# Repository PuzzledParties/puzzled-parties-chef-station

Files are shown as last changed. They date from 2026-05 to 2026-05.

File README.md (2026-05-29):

# Puzzled Parties Chef Station

Chef Station is the hardware/software project for interactive kitchen-game
features. The current build includes the shared power/network layout, the
Master Controller ESP32, and the Simon, chopping, pan motion, pot temperature,
and garnish placement modules.

GitHub is the source of truth for the project: tasks live in Issues, work happens on branches, reviews happen through Pull Requests, and build decisions live in `docs/decisions`.

## Current Build

- Waveshare ESP32-P4-POE-ETH controller board. This is the default board for
  Chef Station unless a future note explicitly says otherwise.
- Four illuminated arcade buttons labeled Ingredient 1 through Ingredient 4.
- One MOSFET low-side lamp driver per button.
- One 1k gate resistor and one 10k gate pulldown per MOSFET.
- Shared lamp positive rail for the button LEDs.
- Common ground rail with local ground buses for each button channel.
- Onboard ES8311 codec and NS4150B speaker amplifier on the Waveshare board.
- One 8 ohm / 2W speaker connected to the Waveshare MX1.25 2-pin speaker header.

## Repo Layout

```text
hardware/
  fritzing/              Editable Fritzing sketches, exports, downloaded parts
  wiring-checklists/     Wiring checklists and legacy notes

firmware/
  esp32-chef-station/    ESP32 firmware home

docs/
  build-notes/           Running notes from assembly/testing
  decisions/             Decision records for hardware/software choices
  collaborator-setup.md  How collaborators get started
  project-management.md  How we use GitHub/Codex to manage work

tools/
  diagram-generators/    Scripts that generate/edit diagram assets
```

## Main Files

- `docs/build-wiring-diagrams.md` - iPad-friendly index of the build wiring diagrams, checklists, and editable Fritzing files.
- `hardware/fritzing/master-power-network/` - master power and network layout.
- `hardware/fritzing/library-art/chef_station_simon_4btn_audio_editable.fzz` - current editable Fritzing sketch.
- `hardware/fritzing/library-art/chef_station_simon_4btn_audio_editable.png` - current PNG preview.
- `hardware/fritzing/library-art/fritzing_svg_export/chef_station_simon_4btn_audio_editable_breadboard.svg` - current Fritzing SVG export.
- `hardware/fritzing/library-art/wiring_checklist_4btn_audio.md` - current wiring checklist.
- `hardware/fritzing/chopping-module/` - chopping module wiring.
- `hardware/fritzing/pan-motion-cooktop/` - pan motion cooktop wiring.
- `hardware/fritzing/pot-temperature-heat-balance/` - pot temperature / heat balance wiring.
- `hardware/fritzing/garnish-placement/` - garnish placement wiring.
- `tools/diagram-generators/generate_orthogonal_fritzing_diagram.py` - generator for the latest native Fritzing sketch.

## Important Electrical Notes

- All grounds must be common: ESP32-P4 GND, lamp supply negative, button switch grounds, MOSFET sources, and pulldown grounds.
- The linked illuminated arcade buttons are treated as 12V LED buttons.
- Button inputs use ESP32-P4 internal pullups: unpressed = HIGH, pressed = LOW.
- Lamp gates use GPIO20, GPIO21, GPIO22, and GPIO23. Avoid GPIO24/GPIO25 for lamps because the Waveshare header labels them as USB `D-`/`D+`.
- Audio uses the onboard ES8311 codec and NS4150B amplifier. Connect the speaker only to the board speaker header; do not tie either speaker lead to ground.
- IRFB11N50APBF is overkill and not logic-level; replace with a logic-level MOSFET if the button LEDs do not fully turn on.

## Daily Workflow

1. Pick or create a GitHub Issue.
2. Create a branch named for the work, such as `firmware/simon-game` or `hardware/audio-test`.
3. Make the change locally.
4. Push the branch and open a Pull Request.
5. Merge into `main` after review or test notes are captured.

## Regenerating The Current Wiring Diagram

Run from the repo root:

```powershell
python .\tools\diagram-generators\generate_orthogonal_fritzing_diagram.py
```

The script writes the editable `.fzz` and asks Fritzing to export SVGs through:

```powershell
& 'C:\Program Files\Fritzing\Fritzing.exe' -svg .\hardware\fritzing\library-art\fritzing_svg_export
```

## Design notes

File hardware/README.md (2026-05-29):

# Hardware

Hardware assets for Chef Station.

## Current Diagram

- Build wiring index: [`../docs/build-wiring-diagrams.md`](../docs/build-wiring-diagrams.md)
- Master power and network: `fritzing/master-power-network/`
- Simon ingredient buttons and audio: `fritzing/library-art/`
- Chopping module: `fritzing/chopping-module/`
- Pan motion cooktop: `fritzing/pan-motion-cooktop/`
- Pot temperature / heat balance: `fritzing/pot-temperature-heat-balance/`
- Garnish placement: `fritzing/garnish-placement/`

## Areas

- `fritzing/` - editable diagrams, Fritzing exports, downloaded parts, and older diagram iterations.
- `wiring-checklists/` - wiring checklist history and notes.

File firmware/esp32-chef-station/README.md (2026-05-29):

# ESP32 Chef Station Firmware

Firmware home for Chef Station.

Planned modules:

- Button input scanning with `INPUT_PULLUP`.
- Lamp output control for Simon-style flashing.
- Audio output on GPIO26 using DAC or PWM into the PAM8403 `L IN`.
- Game state for Simon and future Chef Station features.

No firmware implementation has been committed yet.

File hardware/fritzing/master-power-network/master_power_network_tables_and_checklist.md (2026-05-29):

# Chef Station Master Power And Network Tables / Checklist

## Power Rail Table

| Rail | Source | Voltage | Use | Hard rule |
|---|---|---:|---|---|
| PoE | LS108GP switch ports | PoE | ESP32 controller boards only | Do not power LED strips, servos, lamps, or amplifiers from ESP32 PoE boards. |
| 12V_SHOW | 12V Adapter A | 12V DC | Actual 12V LED strips, 12V amplifier, fans, monitor accessory if rated 12V | Only connect devices explicitly rated for 12V. Do not tie to other adapter positives. |
| 5V_LED | 12V Adapter B -> Buck #2 | 5.0V-5.1V DC | WS2812/NeoPixel strips, cooktop coil LEDs, overhead strip, 5V Simon button lamps | Do not parallel with another buck output. |
| 5V_AUDIO_SERVO | 12V Adapter C -> Buck #3 | 5.0V-5.1V DC | DFPlayer modules, small amplifiers, small speakers, servo timer, optional LCD backlights | Do not feed from ESP32 5V/PoE board power. |
| 5V_AUX | 12V Adapter D -> Buck #1 | 5.0V-5.1V DC | Optional LCD backlights, small non-PoE accessories, low-current status LEDs, small relay boards | Keep low-current and isolated from other 5V positives. |
| COMMON_GND | Ground terminal block / bus | 0V reference | Shared reference where GPIO/data/control crosses rails | Do not route load return current through ESP32 ground pins. |

## Network Port Table

| LS108GP port | Device | Cable behavior | Power behavior |
|---|---|---|---|
| 1 | Simon ESP32 PoE board | Ethernet network | PoE powers ESP32 controller only. |
| 2 | Chopping ESP32 PoE board | Ethernet network | PoE powers ESP32 controller only. |
| 3 | Pan Motion ESP32 PoE board | Ethernet network | PoE powers ESP32 controller only. |
| 4 | Pot Temperature ESP32 PoE board | Ethernet network | PoE powers ESP32 controller only. |
| 5 | Garnish Placement ESP32 PoE board | Ethernet network | PoE powers ESP32 controller only. |
| 6 | Master Controller ESP32 PoE board | Ethernet network | PoE powers ESP32 controller only. |
| 7 | Epson TM-T20IV / TM-T20V-family printer | Ethernet network | Separate Epson manufacturer power supply. Not PoE. |
| 8 | Optional router/DHCP source or spare | DHCP/network management if needed | Router uses its own power if used. |

## Per-Module Accessory Power Table

| Module | ESP32 power/network | Accessory power | Control/ground notes |
|---|---|---|---|
| Simon | PoE over Ethernet | Button lamps from 5V_LED or 12V_SHOW by lamp rating; audio if present from 5V_AUDIO_SERVO | Button switches to ESP32 GPIO/GND. Lamp MOSFET sources to COMMON_GND. ESP32 GPIOs drive MOSFET gates only. |
| Chopping | PoE over Ethernet | Piezo from ESP32 3.3V if suitable; I2C LCD backlight from 5V_AUX or 5V_LED | Use optional I2C level shifter for 5V I2C LCD. LCD/piezo ground common with ESP32. |
| Pan Motion | PoE over Ethernet | Hall sensors from ESP32 3.3V; cooktop LED from 5V_LED or 12V_SHOW by strip type; DFPlayer/audio from 5V_AUDIO_SERVO | ESP32 sends LED data and serial to DFPlayer. All grounds common. |
| Pot Temperature | PoE over Ethernet | Encoder on ESP32 GPIO; cooktop LED from 5V_LED or 12V_SHOW; temp strip/ring from 5V_LED | Encoder uses INPUT_PULLUP. ESP32 and LED rail grounds common. |
| Garnish Placement | PoE over Ethernet | Touch electrodes only to ESP32 touch pins through 1k resistors; RGB strip from 5V_LED; servo from 5V_AUDIO_SERVO | DONE button to ESP32 GPIO/GND. ESP32, servo, and LED grounds common. |
| Master Controller | PoE over Ethernet | Start Game button only; Epson printer is Ethernet | GPIO5 to one side of the Start Game button, other side to GND. Configure GPIO5 with INPUT_PULLUP. |

## Master Controller ESP32 Pin Map

| Function | Master Controller ESP32 connection | Destination | Notes |
|---|---|---|---|
| Power/network | RJ45 Ethernet / PoE | LS108GP port 6 | PoE powers the ESP32 controller only. |
| Start Game button signal | GPIO5 | One side of momentary normally-open Start Game button | `INPUT_PULLUP`; unpressed = HIGH, pressed = LOW. |
| Start Game button ground | GND | Other side of Start Game button / COMMON_GND | This is the only local GPIO wiring on the Master Controller ESP32. |
| Module commands and score replies | Ethernet UDP port 42100 | Simon, chopping, pan, pot-temp, and garnish ESP32 boards | No GPIO start/reset harness between controller and modules. |
| Receipt printer | Ethernet TCP port 9100 | Epson TM-T20IV / TM-T20V-family printer | Printer uses its own Epson power supply; no ESP32 GPIO pins. |

## Grounding Notes

- All grounds must be common where GPIO/data/control signals cross between PoE ESP32 boards and external 5V/12V accessories.
- Connect Adapter A/B/C/D negatives, Buck #1/#2/#3 grounds, LED strip ground, DFPlayer/audio ground, servo ground, Simon lamp ground, and any relevant ESP32 GND pins to COMMON_GND.
- Module commands travel over Ethernet, so no separate GPIO sync harness is required for module start/reset.
- Do not route high-current LED, servo, or audio return current through ESP32 ground pins. Use a ground terminal block or bus.
- Grounds may be common; separate 12V positives and separate buck 5V positives must not be tied together.

## Setup Checklist

- Verify every adapter output with a multimeter before connecting electronics.
- Tape or lock adjustable adapter selector dials at 12V.
- Adjust buck converters to 5.0V-5.1V before connecting 5V electronics.
- Label both ends of every power cable.
- Confirm 12V_SHOW never touches 5V devices.
- Confirm 5V rails never touch ESP32 3.3V pins.
- Keep each 12V adapter as its own limited-current branch.
- Do not parallel separate wall adapter outputs.
- Do not parallel separate buck converter outputs.
- Use proper wire gauge for LED, servo, and audio currents.
- Avoid breadboard rails for multi-amp loads.
- Add 1000uF across LED strip 5V/GND near strip input.
- Add 470uF-1000uF near servo power.
- Add 470uF-1000uF near DFPlayer/audio modules.
- Add 0.1uF near Hall, piezo, and small sensor modules.
- Add a 330-470 ohm resistor on each WS2812 data line.
- If no fuses are available, avoid the 5V/60A open-frame supply in this temporary build.

## Warning Callouts

- PoE budget: keep total ESP32 PoE load under the LS108GP 62W budget and 30W per-port max.
- Common ground: required wherever GPIO/data/control signals cross between ESP32 boards and external accessory power rails.
- 12V vs 5V separation: only 12V-rated devices connect to 12V_SHOW; 5V devices connect only to named buck-derived 5V rails.
- No high-current loads from ESP32 PoE boards: ESP32 GPIOs send signals only.
- No unfused 60A supply in the temporary build: add fused distribution before using any large open-frame supply.
- Do not parallel buck outputs.
- Verify adjustable adapters with a multimeter.

## Network Behavior Notes

- ESP32 modules can receive IP addresses from a router/DHCP source or use static IPs.
- If there is no router, create and label a static IP plan before the event.
- The Master Controller ESP32 communicates with modules over Ethernet.
- The Epson printer is addressed by IP.
- The LS108GP may be unmanaged; use an optional router/DHCP source if network management is needed.
- Do not rely on internet access during the event.

## Assumptions And Substitutions

- The master controller in this build is a Waveshare ESP32-P4-POE-ETH / NH board.
- Hardware START_SYNC / RESET_SYNC wiring is intentionally omitted. Module start/reset/score traffic is planned over Ethernet.
- Exact LS108GP and Waveshare ESP32-P4-POE-ETH/NH Fritzing parts were not available in the installed library, so the sketch embeds custom editable helper parts with labeled connectors.
- No third-party parts were downloaded.
- The diagram is a master power/network layout, not a PCB fabrication footprint.

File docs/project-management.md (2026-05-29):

# Project Management

Use this repository as the project home for Chef Station.

## GitHub

- Issues are the task list.
- Branches are where work happens.
- Pull Requests are where changes get reviewed, tested, and merged.
- Decision records in `docs/decisions` explain why we chose a hardware/software direction.
- Build notes in `docs/build-notes` capture messy real-world findings while assembling and testing.

## Suggested Issue Labels

- `hardware` - wiring, components, panel layout, enclosure, soldering.
- `firmware` - ESP32 code, game state, audio, inputs, outputs.
- `docs` - checklists, setup guides, decisions.
- `test` - bench testing, validation, measurements.
- `question` - unresolved design choice.
- `bug` - something that used to work or should work but does not.

## Branch Names

Use short, descriptive names:

```text
hardware/button-harness
hardware/panel-layout
firmware/simon-game
firmware/audio-driver
docs/collaborator-setup
test/button-led-current
```

## Codex Client Workflow

In the Codex client, start work from the local repo folder:

```text
C:\Users\homes\OneDrive\Desktop\Puzzled Parties\Puzzle Assets\Chef Station Simon Wiring
```

That folder is the project root. Ask Codex to work on a GitHub Issue, a branch, or a specific file in this repo. Good prompts look like:

```text
Create a branch for issue #3 and implement the ESP32 Simon game skeleton.
```

```text
Review the current wiring checklist and update it for the latest Fritzing diagram.
```

```text
Open a PR for the firmware/audio-driver branch with a short test plan.
```

## Keeping Main Stable

Keep `main` usable for collaborators. Put experiments on branches, and use PRs even for small changes so the discussion and test notes stay attached to the work.

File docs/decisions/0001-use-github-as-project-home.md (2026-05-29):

# 0001 Use GitHub As The Project Home

## Status

Accepted

## Context

Chef Station is becoming more than a single wiring diagram. It will include hardware, firmware, build notes, diagrams, and multiple interactive features.

## Decision

Use the public GitHub repository `PuzzledParties/puzzled-parties-chef-station` as the source of truth. Track tasks in Issues, changes in branches and Pull Requests, and design choices in decision records.

## Consequences

- Collaborators can clone one repo and see the current project state.
- Build context lives with the assets and code.
- Pull Requests give each change a place for review notes, test results, and discussion.

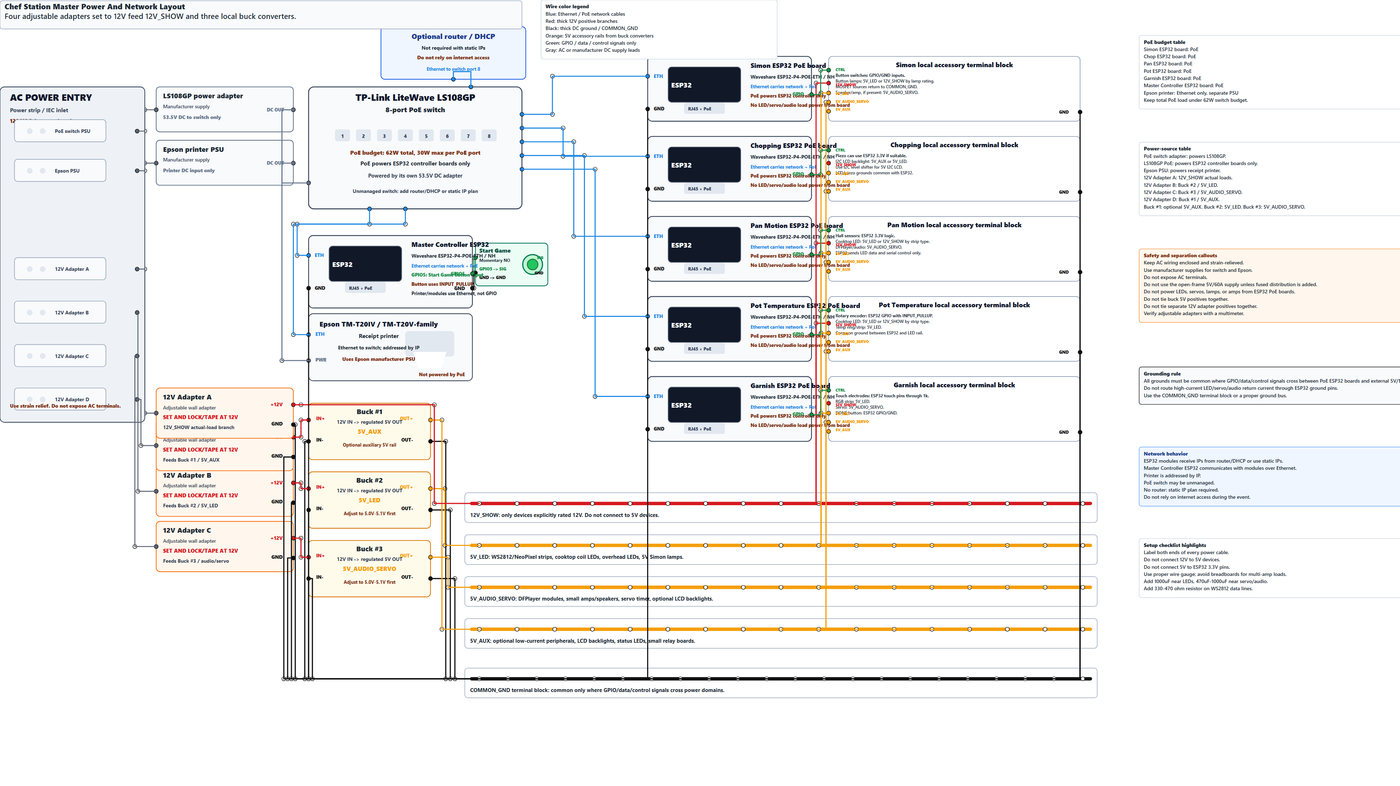
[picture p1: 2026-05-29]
hardware/fritzing/master-power-network/chef_station_master_power_network_layout.png

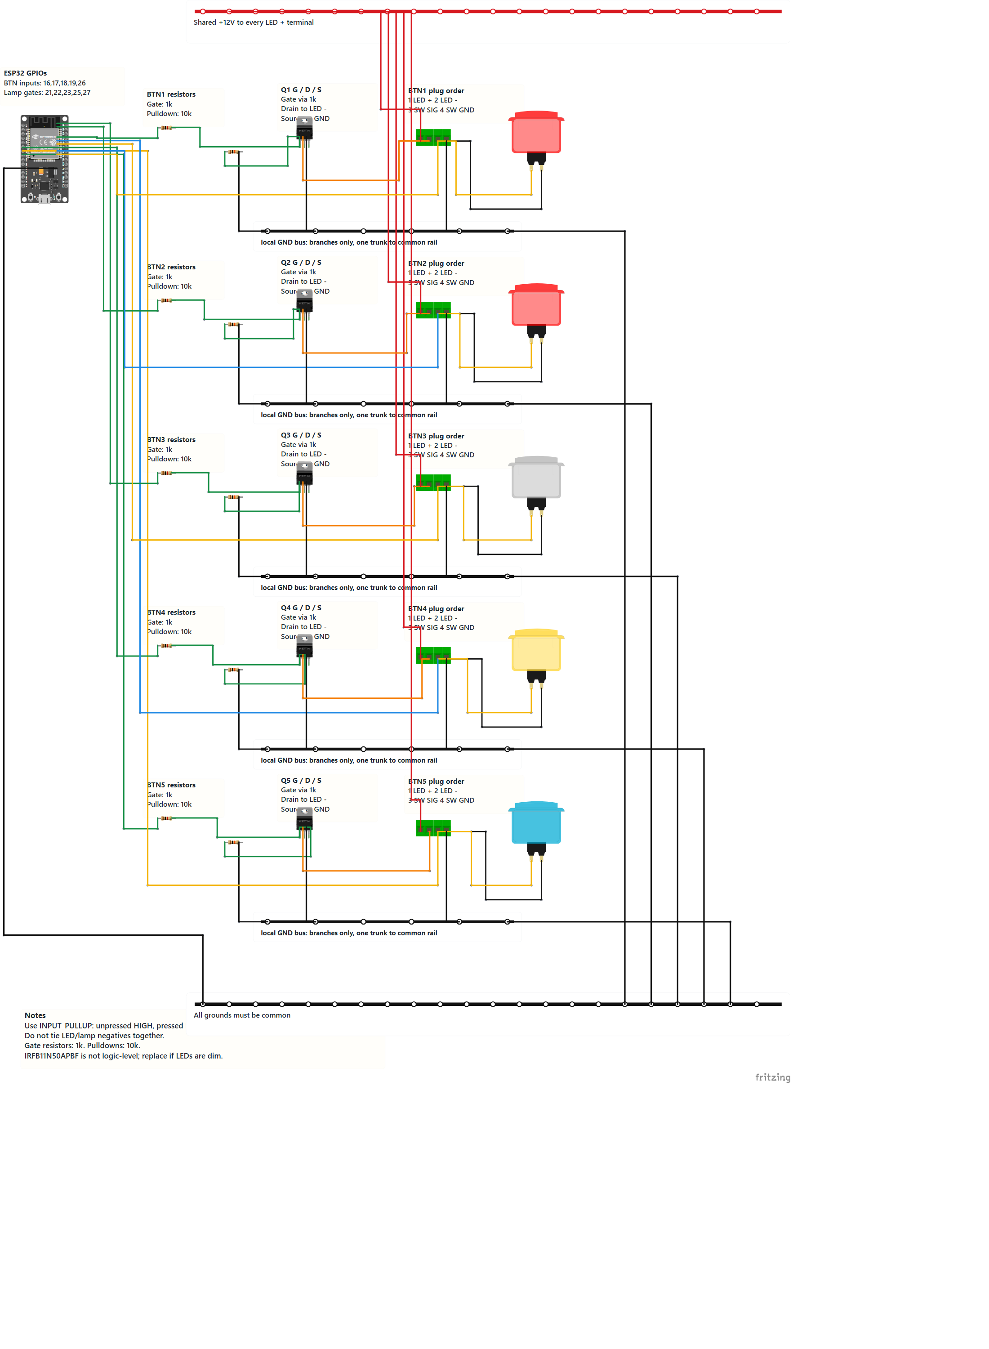
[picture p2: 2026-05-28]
hardware/fritzing/library-art/chef_station_simon_lane_routed_editable.png

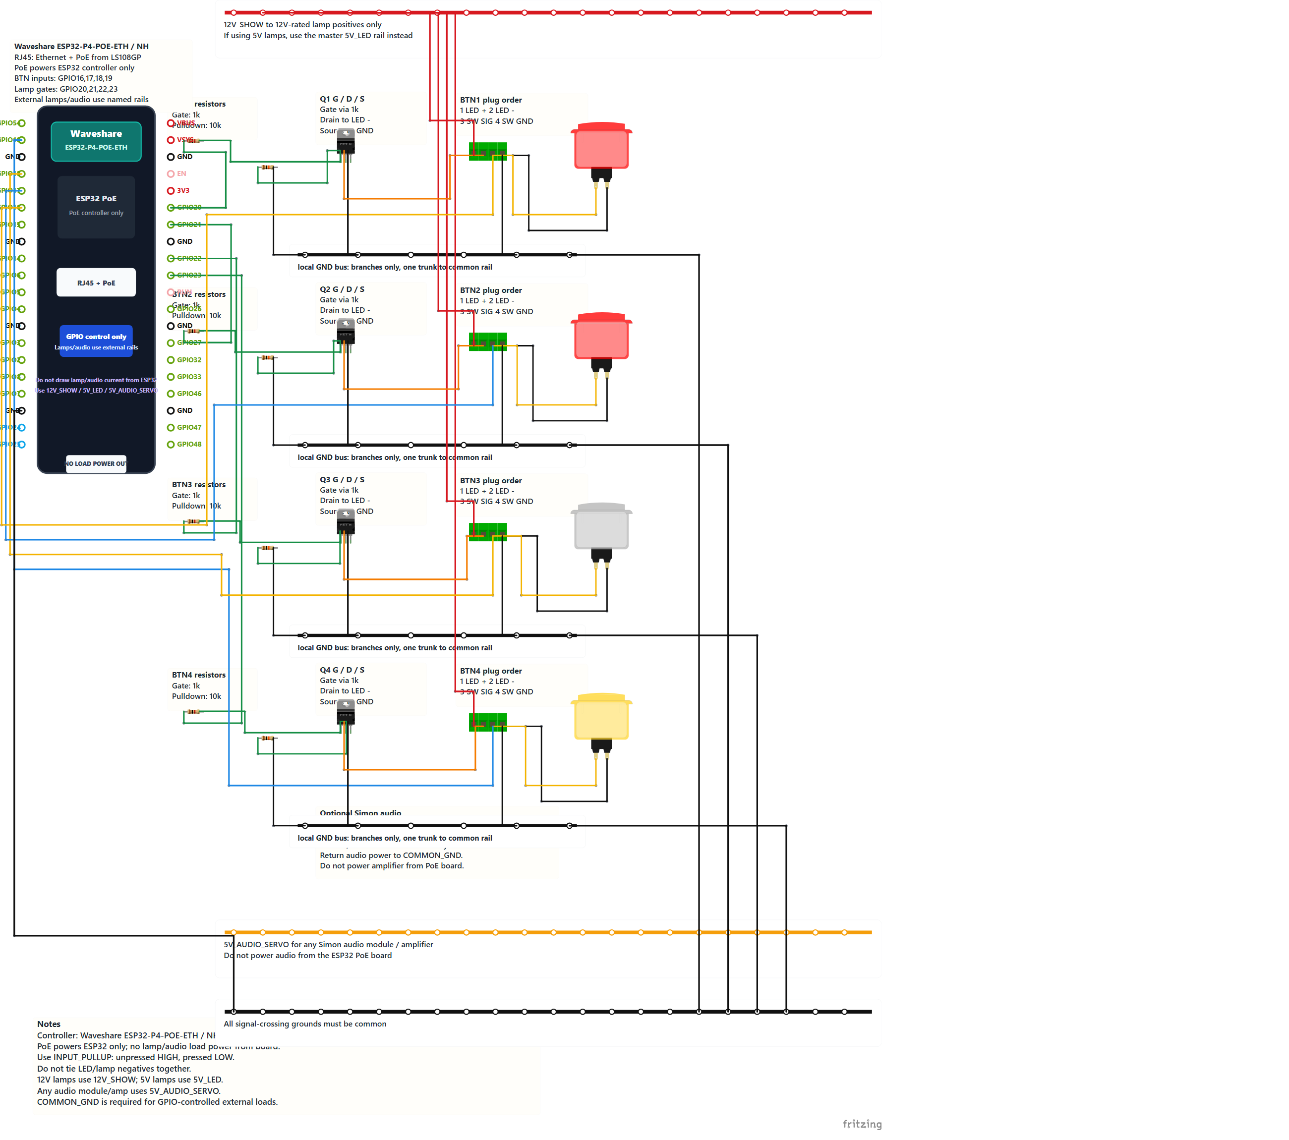
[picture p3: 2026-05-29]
hardware/fritzing/library-art/chef_station_simon_4btn_audio_editable.png

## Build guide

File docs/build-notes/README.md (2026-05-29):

# Build Notes

Use this folder for day-of-build notes, test results, measurements, and surprises.

Suggested filenames:

```text
2026-05-28-button-led-voltage-test.md
2026-05-28-audio-amp-test.md
2026-05-28-panel-layout-notes.md
```

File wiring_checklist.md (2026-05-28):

# Chef Station Simon Wiring Checklist

Assumption: the prompt requested five buttons but only listed suggested pins for four, so BTN5 uses GPIO 26 for the switch input and GPIO 27 for the lamp output.

Button reference used for this revision: uxcell 60mm 12V LED illuminated arcade pushbuttons with a normally-open microswitch and screw terminals. Use a 12V lamp supply for these specific LED modules.

## Pin Map

| Button | Switch input | Lamp gate output |
| --- | --- | --- |
| BTN1 / Ingredient 1 | GPIO 16 | GPIO 21 |
| BTN2 / Ingredient 2 | GPIO 17 | GPIO 22 |
| BTN3 / Ingredient 3 | GPIO 18 | GPIO 23 |
| BTN4 / Ingredient 4 | GPIO 19 | GPIO 25 |
| BTN5 / Ingredient 5 | GPIO 26 | GPIO 27 |

## Wiring

- Tie ESP32 GND, external lamp supply negative, all switch ground terminals, MOSFET sources, and all 10k pulldown ground ends to the common ground rail.
- Feed every LED/lamp positive from the shared +12V lamp rail for the linked uxcell buttons. If you substitute 5V illuminated buttons, use the matching 5V lamp rail instead.
- Run each lamp negative separately to its own MOSFET drain. Do not tie lamp negatives together.
- Connect each MOSFET source to common ground.
- Connect each ESP32 lamp GPIO to its MOSFET gate through a 100 ohm resistor.
- Add a 10k resistor from each MOSFET gate to common ground.
- Wire each button switch with one side to GND and the other side to its ESP32 input GPIO.
- Configure each button input as INPUT_PULLUP in firmware: unpressed = HIGH, pressed = LOW.
- Observe LED polarity on the arcade button lamp terminals; if an LED does not light, swap its LED + and LED - leads.
- IRFB11N50APBF can work for small lamp loads, but it is not a logic-level MOSFET. If lamps are dim or do not fully turn on, replace it with a logic-level N-channel MOSFET.

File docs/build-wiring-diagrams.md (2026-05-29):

# Chef Station Build Wiring Diagrams

No GitHub account is needed. On an iPad, if GitHub asks to open the app, choose
to continue in the browser. Tap a PNG link to open the diagram, then pinch to
zoom or use Share to save it.

## Build Set

| Build area | Diagram PNG | Checklist / tables | Editable Fritzing sketch |
|---|---|---|---|
| Master power and network, including Master Controller ESP32 | [Open diagram](../hardware/fritzing/master-power-network/chef_station_master_power_network_layout.png) | [Open checklist](../hardware/fritzing/master-power-network/master_power_network_tables_and_checklist.md) | [Open Fritzing file](../hardware/fritzing/master-power-network/chef_station_master_power_network_editable.fzz) |
| Simon ingredient buttons and audio | [Open diagram](../hardware/fritzing/library-art/chef_station_simon_4btn_audio_editable.png) | [Open checklist](../hardware/fritzing/library-art/wiring_checklist_4btn_audio.md) | [Open Fritzing file](../hardware/fritzing/library-art/chef_station_simon_4btn_audio_editable.fzz) |
| Chopping module | [Open diagram](../hardware/fritzing/chopping-module/chef_station_chopping_module_wiring_diagram.png) | [Open checklist](../hardware/fritzing/chopping-module/wiring_checklist_chopping_module.md) | [Open Fritzing file](../hardware/fritzing/chopping-module/chef_station_chopping_module_editable.fzz) |
| Pan motion cooktop | [Open diagram](../hardware/fritzing/pan-motion-cooktop/chef_station_pan_motion_cooktop_wiring_diagram.png) | [Open checklist](../hardware/fritzing/pan-motion-cooktop/wiring_checklist_pan_motion_cooktop.md) | [Open Fritzing file](../hardware/fritzing/pan-motion-cooktop/chef_station_pan_motion_cooktop_editable.fzz) |
| Pot temperature / heat balance | [Open diagram](../hardware/fritzing/pot-temperature-heat-balance/chef_station_pot_temperature_heat_balance_wiring_diagram.png) | [Open checklist](../hardware/fritzing/pot-temperature-heat-balance/wiring_checklist_pot_temperature_heat_balance.md) | [Open Fritzing file](../hardware/fritzing/pot-temperature-heat-balance/chef_station_pot_temperature_heat_balance_editable.fzz) |
| Garnish placement | [Open diagram](../hardware/fritzing/garnish-placement/chef_station_garnish_placement_wiring_diagram.png) | [Open checklist](../hardware/fritzing/garnish-placement/wiring_checklist_garnish_placement.md) | [Open Fritzing file](../hardware/fritzing/garnish-placement/chef_station_garnish_placement_editable.fzz) |

## Before Powering Anything

- Verify every adjustable adapter or buck converter output with a multimeter.
- Keep 12V devices on `12V_SHOW` and 5V devices on the named 5V rails.
- Do not tie separate positive supply outputs together.
- Use `COMMON_GND` where GPIO, data, or control signals cross between boards and accessory power.
- Do not route high-current LED, servo, lamp, or audio return current through ESP32 ground pins.
- Label both ends of every power, ground, signal, and accessory cable.

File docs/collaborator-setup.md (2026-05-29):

# Collaborator Setup

## Clone The Repo

```powershell
git clone https://github.com/PuzzledParties/puzzled-parties-chef-station.git
cd puzzled-parties-chef-station
```

## Create A Branch

```powershell
git checkout -b firmware/simon-game
```

Use a branch name that describes the task.

## Open The Wiring Diagram

Install Fritzing, then open:

```text
hardware/fritzing/library-art/chef_station_simon_4btn_audio_editable.fzz
```

## Current Electrical Assumptions

- All Chef Station boards are Waveshare ESP32-P4-POE-ETH unless a task or
  decision record explicitly says otherwise.
- Arcade button LEDs use the lamp supply rail, currently documented as 12V.
- Button inputs use GPIO16, GPIO17, GPIO18, and GPIO19.
- Lamp gate outputs use GPIO20, GPIO21, GPIO22, and GPIO23.
- Avoid GPIO24/GPIO25 for lamps because the Waveshare header labels them as USB `D-`/`D+`.
- Audio uses the Waveshare board's onboard ES8311 codec and NS4150B amplifier.
- ESP32-P4 GND, lamp supply negative, MOSFET sources, switch grounds, and pulldown grounds all share common ground.
- Button inputs use `INPUT_PULLUP`.
- Speaker connects to the Waveshare MX1.25 2-pin speaker header.

## Making Changes

1. Pull latest `main`.
2. Create a branch.
3. Make and test the change.
4. Commit with a clear message.
5. Push the branch.
6. Open a Pull Request.

```powershell
git checkout main
git pull
git checkout -b hardware/button-harness
git add .
git commit -m "Document button harness wiring"
git push -u origin hardware/button-harness
```

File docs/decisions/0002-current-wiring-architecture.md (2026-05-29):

# 0002 Current Wiring Architecture

## Status

Accepted

## Context

The Chef Station button module needs individually flashing illuminated buttons, button input sensing, and sound output.

## Decision

- Use four illuminated arcade buttons.
- Use ESP32 internal pullups for button switch inputs.
- Use one low-side MOSFET driver per button lamp.
- Use a shared lamp positive rail and individual lamp negative switching.
- Use local ground buses for each button channel, tied to one common ground rail.
- Use the Waveshare ESP32-P4-POE-ETH as the controller board for this and
  future Chef Station builds unless another board is explicitly specified.
- Use GPIO16-GPIO19 for the four switch inputs.
- Use GPIO20-GPIO23 for the four lamp gate outputs.
- Avoid GPIO24/GPIO25 for lamp outputs because they are exposed as USB OTG
  `D-`/`D+` on the Waveshare header.
- Use the board's onboard ES8311 codec and NS4150B amplifier for speaker output.
- Use one 8 ohm / 2W speaker connected to the board's MX1.25 2-pin speaker header.

## Consequences

- Button lamps can flash independently.
- Switch wiring remains simple: pressed = LOW, unpressed = HIGH.
- All grounds must be common.
- A separate PAM8403 module is no longer part of the default build.
- Neither speaker lead should be tied to ground; use the board speaker header only.

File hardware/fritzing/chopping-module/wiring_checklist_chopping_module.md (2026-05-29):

# Chef Station Chopping Module Wiring Checklist

## Pin Assignment Table

| ESP32 pin | Function |
|---|---|
| GPIO16 / ADC1_CH0 | Piezo AO analog input through 1k-10k series resistor |
| SDA / GPIO7 | I2C SDA to LCD through level shifter LV1/HV1 if LCD is powered at 5V |
| SCL / GPIO8 | I2C SCL to LCD through level shifter LV2/HV2 if LCD is powered at 5V |
| Ethernet UDP 42100 | START_GAME, FORCE_END, REQUEST_SCORE, RESET_GAME, and score JSON |

## Wiring Checklist

- ESP32 is powered and networked by PoE from the TP-Link LS108GP switch.
- PoE powers the ESP32 controller only. Do not power LCD backlights or other accessories from the ESP32 PoE board.
- ESP32 `GND` connects to the `COMMON_GND` rail wherever LCD or piezo signals cross to externally powered accessories.
- `5V_AUX` positive from the master power distribution connects to the local `5V_AUX` rail for the LCD/backlight and optional I2C level shifter HV side.
- `5V_AUX` ground/return connects to `COMMON_GND`.
- Do not feed +5V into the ESP32 `3V3` pin.
- Piezo module `VCC` connects to ESP32 3.3V, not +5V.
- Piezo module `GND` connects to `COMMON_GND`.
- Piezo module `AO` connects through a 1k-10k series resistor to GPIO16 / ADC1_CH0.
- Piezo module `DO` is left disconnected unless used as an optional debug input.
- Use `AO` analog output for scoring. Do not use `DO` as the main chop input.
- LCD `GND` connects to `COMMON_GND`.
- LCD `VCC` connects to `5V_AUX`, or to 3.3V only if the LCD/backpack works reliably at 3.3V.
- ESP32 SDA / GPIO7 connects to level shifter `LV1`; matching `HV1` connects to LCD `SDA`.
- ESP32 SCL / GPIO8 connects to level shifter `LV2`; matching `HV2` connects to LCD `SCL`.
- If the LCD backpack is powered at +5V, use the bidirectional I2C level shifter shown.
- Level shifter LV connects to ESP32 3.3V, HV connects to `5V_AUX`, and GND connects to `COMMON_GND`.
- Master game commands arrive over Ethernet; do not wire separate START_SYNC, RESET_SYNC, or DONE_OUT terminals.

## Piezo And Cutting Board Notes

- Piezo detects impacts, not static pressure.
- Mechanically couple the piezo disc or module to the underside of the cutting board.
- Protect the piezo from direct knife strikes.
- Put the cutting board on damped/rubber feet to reduce table vibration.
- Tune the analog threshold only after the piezo is mounted in the final board.
- Start with debounce/refractory period around 100-150 ms.
- If fast chopping is required, allow shorter debounce such as 60-100 ms after testing.
- Use threshold above vibration/noise baseline.
- Do not count multiple ringing peaks from one chop.
- Use forgiving thresholds because public users will chop inconsistently.

## Raw Piezo Disc Alternative

- Use the raw piezo circuit instead of the piezo module, not in parallel with it.
- One piezo lead goes to GPIO16 / ADC through a 10k-100k series resistor.
- The other piezo lead goes to GND.
- Add a 1M resistor across the piezo leads as bleed/reference.
- Add an optional 3.3V clamp diode or Schottky protection to protect the ESP32 ADC.
- Do not connect a raw piezo directly to the ESP32 ADC without input protection.

## LCD Behavior Notes

- LCD line 1: `CHOP FASTER`
- LCD line 2: `KEEP GOING`
- LCD line 3: progress bar fills as `chopCount / 100`
- LCD line 4: `Chops: 037/100` or `Time: 12.4s`
- Common I2C LCD addresses are `0x27` and `0x3F`.
- Adjust the LCD contrast potentiometer if characters are invisible.
- Mount the LCD above or behind the board so players do not need to look straight down.

## Firmware Behavior Notes

- IDLE: LCD may show `READY TO CHOP` with an empty progress bar.
- START: on Ethernet `START_GAME phase=main`, set `chopCount = 0` and `startTimeMs = millis()`.
- ACTIVE: sample GPIO16 frequently and count one valid chop when the analog value exceeds threshold.
- ACTIVE: update the LCD progress bar immediately after every valid chop.
- ACTIVE: reject ringing using the debounce/refractory period.
- COMPLETE: when `chopCount` reaches 100, set `finishTimeMs = millis()`.
- COMPLETE: compute `elapsedSeconds = (finishTimeMs - startTimeMs) / 1000.0`.
- COMPLETE: show completion time locally on the LCD and send score JSON.
- RESET: on Ethernet `RESET_GAME`, clear count and return to IDLE.
- Ethernet complete event: `{"station":"chef","module":"chop","event":"complete","chops":100,"seconds":18.42}`
- If the game ends before 100 chops, report partial score: `{"station":"chef","module":"chop","event":"incomplete","chops":72,"seconds":30.00}`

## Scoring

- Primary score is elapsed time from Ethernet `START_GAME` to the 100th valid chop.
- Lower time is better.
- The master clock may decide final ranking later.
- The chopping module measures local elapsed time and chop count.
- The monitor or central controller can add polish, but core gameplay should work locally.

## Assumptions And Part Notes

- Controller assumption: Waveshare ESP32-P4-ETH / ESP32-P4-POE-ETH module powered from the LS108GP over Ethernet.
- ESP32-P4 pinout basis: Waveshare exposes SDA/GPIO7 and SCL/GPIO8 on the 40-pin header; ESP32-P4 ADC pins are different from classic ESP32 DevKit GPIO34-style ADC pins.
- ESP32 part: custom editable ESP32-P4 helper part with the module's functional GPIO labels; verify exact board pinout before final harness fabrication.
- Accessory rail assumption: LCD/backlight power comes from `5V_AUX`, not from the ESP32 PoE board.
- Piezo module, LCD, level shifter, rails, physical board layout, raw piezo alternative, and callouts are custom editable Fritzing helper parts for readability.
- LCD is shown powered from +5V, so the diagram includes the optional level shifter in the active I2C path.

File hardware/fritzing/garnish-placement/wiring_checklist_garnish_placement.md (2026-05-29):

# Chef Station Garnish Placement Wiring Checklist

## Pin Assignment Table

| ESP32 pin | Function |
|---|---|
| GPIO2 / Touch CH1 | CENTER capacitive electrode |
| GPIO3 / Touch CH2 | INNER RING capacitive electrode |
| GPIO6 / Touch CH5 | OUTER RING capacitive electrode |
| GPIO23 | RGB LED strip data through 330-470 ohm resistor |
| GPIO32 | Servo signal |
| GPIO26 | DONE button input using `INPUT_PULLUP` |

## Wiring Checklist

- ESP32 is powered and networked by PoE from the TP-Link LS108GP switch.
- PoE powers the ESP32 controller only. Do not power RGB strips or servos from the ESP32 PoE board.
- `5V_LED` positive from the master power distribution goes to the local `5V_LED` rail for the RGB strip only.
- `5V_AUDIO_SERVO` positive from the master power distribution goes to the local servo rail.
- Both 5V rail returns connect to `COMMON_GND`; do not tie the two 5V positives together.
- ESP32 GND connects to the `COMMON_GND` rail wherever LED data, servo signal, DONE input, or touch references cross power domains.
- Do not feed +5V into the ESP32 `3V3` pin.
- LED strip `+5V` connects to the `5V_LED` rail.
- LED strip `GND` connects to `COMMON_GND`.
- ESP32 GPIO23 connects through a 330-470 ohm resistor to LED strip `DIN`.
- Place a 1000uF electrolytic capacitor across LED strip +5V and GND near the strip.
- Servo red wire connects to `5V_AUDIO_SERVO`, brown/black wire to `COMMON_GND`, and signal to GPIO32.
- Place a 470uF-1000uF electrolytic capacitor across servo +5V and GND near the servo.
- DONE button one side connects to GPIO26; the other side connects to `COMMON_GND`.
- Configure DONE as `INPUT_PULLUP`; logic is unpressed = HIGH, pressed = LOW, with software debounce.
- CENTER electrode connects only to GPIO2 / Touch CH1 through its own 1k series resistor.
- INNER RING electrode connects only to GPIO3 / Touch CH2 through its own 1k series resistor.
- OUTER RING electrode connects only to GPIO6 / Touch CH5 through its own 1k series resistor.
- Capacitive electrodes do not connect to +5V or GND.
- Keep electrode wires short and leave visible gaps between copper/foil zones.
- Score after hands and chopsticks are away; calibrate capacitive baselines before each round.

## Firmware Behavior Notes

- At round start, sample capacitive baselines with no garnish present.
- Player has 30 seconds to place the conductive garnish.
- Servo sweeps from start to end over the 30-second timer.
- RGB strip shows active/countdown state: white at start, yellow at 10 seconds, flashing red at 5 seconds.
- DONE button ends the garnish round early.
- At scoring time, wait 300-800 ms, sample all three touch electrodes, calculate deltas from baseline, and score by strongest zone.
- CENTER strongest = PERFECT; INNER strongest = GOOD; OUTER strongest = OK; weak/no signal = MISS / NO GARNISH.

## Assumptions And Substitutions

- Controller assumption: Waveshare ESP32-P4-POE-ETH / ESP32-P4-POE-ETH-NH module powered from the LS108GP over Ethernet.
- ESP32 part: custom editable ESP32-P4 PoE helper part. ESP32-P4 touch-capable GPIOs are GPIO2-GPIO15; this layout uses GPIO2, GPIO3, and GPIO6 while GPIO24/GPIO25 remain untouched.
- Accessory rail assumption: RGB strip uses `5V_LED`; servo uses `5V_AUDIO_SERVO`; these positives are not tied together.
- The LED strip is represented as a custom editable 3-contact WS2812B/NeoPixel-style strip connector.
- The fake steak target is represented as a custom editable bullseye electrode part because no stock Fritzing part matches that prop.
- The servo, target, rails, supply, DONE button, and callouts use custom diagram parts for readable labeled terminals.

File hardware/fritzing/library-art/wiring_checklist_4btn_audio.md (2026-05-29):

# Chef Station Simon 4-Button Wiring Checklist

This revision uses a Waveshare ESP32-P4-POE-ETH / ESP32-P4-POE-ETH-NH controller powered and networked by the LS108GP PoE switch. PoE powers the ESP32 controller and the board's onboard ES8311 codec / NS4150B speaker amplifier. Button lamps and other external loads use named accessory rails.

## Pin Map

| Function | ESP32 pin |
| --- | --- |
| BTN1 / Ingredient 1 switch input | GPIO 16 |
| BTN2 / Ingredient 2 switch input | GPIO 17 |
| BTN3 / Ingredient 3 switch input | GPIO 18 |
| BTN4 / Ingredient 4 switch input | GPIO 19 |
| BTN1 lamp MOSFET gate | GPIO 20 |
| BTN2 lamp MOSFET gate | GPIO 21 |
| BTN3 lamp MOSFET gate | GPIO 22 |
| BTN4 lamp MOSFET gate | GPIO 23 |

## Power Rails

| Rail | Use |
| --- | --- |
| PoE from LS108GP | ESP32 controller, Ethernet, and onboard ES8311/NS4150B audio only |
| 12V_SHOW | 12V-rated Simon button lamps or show loads only |
| 5V_LED | Use instead of 12V_SHOW if the button lamps are 5V-rated |
| 5V_AUDIO_SERVO | Reserved for optional external audio accessories; not used by the default Simon speaker path |
| COMMON_GND | Signal reference and accessory return bus |

## Button And Lamp Wiring

- Configure each button input as `INPUT_PULLUP`: unpressed = HIGH, pressed = LOW.
- Wire each switch with one terminal to COMMON_GND and the other terminal to its ESP32 GPIO input.
- Feed each button lamp positive from the rail matching the lamp voltage: `12V_SHOW` for 12V lamps or `5V_LED` for 5V lamps.
- Run each button lamp negative separately to its own MOSFET drain.
- Connect each MOSFET source to the local ground bus, then to COMMON_GND.
- Connect each ESP32 lamp GPIO to its MOSFET gate through a 1k resistor.
- Add a 10k pulldown from each MOSFET gate to COMMON_GND.
- Do not connect lamp negatives together if individual flashing is required.

## Audio Wiring

- The default Simon sound path uses the Waveshare board's onboard ES8311 codec and NS4150B amplifier.
- Connect one 8 ohm / 2W speaker to the board's MX1.25 2-pin speaker header only.
- Do not tie either speaker lead to COMMON_GND or to any accessory rail.
- A separate PAM8403 or DFPlayer module is not part of the default Simon build.

## Grounding Notes

- Tie the Simon ESP32 GND reference to COMMON_GND anywhere GPIO controls externally powered lamps or audio.
- Do not route high-current lamp/audio return current through ESP32 ground pins.
- Use a ground terminal block or bus for lamp and audio returns.

## Setup Checklist

- Verify each adjustable adapter output with a multimeter before connecting the module.
- Confirm lamp voltage before connecting to `12V_SHOW` or `5V_LED`.
- Do not connect 12V to 5V lamps or 5V to ESP32 3.3V pins.
- Do not parallel separate buck converter outputs.
- Do not parallel separate wall adapter positive outputs.
- Label both ends of every lamp, signal, and rail cable.

## Part Notes

- ESP32 controller: custom editable Waveshare ESP32-P4-POE-ETH / ESP32-P4-POE-ETH-NH helper art with functional GPIO labels. Verify exact board pinout before final harness fabrication.
- Resistors: value-specific Fritzing 1k and 10k resistor artwork, plus visible labels.
- MOSFET: stock Fritzing TO-220 N-channel MOSFET artwork, titled as IRFB11N50APBF.
- Arcade buttons: stock Fritzing arcade button visuals plus labeled 4-position terminal blocks showing lamp +, lamp -, SW SIG, and SW GND.
- Rails, buses, and callouts are custom editable Fritzing helper parts for readability.

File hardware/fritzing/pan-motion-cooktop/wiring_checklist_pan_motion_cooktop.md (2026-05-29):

# Chef Station Pan Motion / Cooktop Wiring Checklist

## Pin Assignment Table

| ESP32 pin | Function |
|---|---|
| GPIO20 / ADC1_CH4 | HALL 1 analog output through optional 1k series resistor |
| GPIO21 / ADC1_CH5 | HALL 2 analog output through optional 1k series resistor |
| GPIO23 | Cooktop RGB LED strip data through 330-470 ohm resistor |
| GPIO26 / UART2 TX | ESP32 TX to DFPlayer RX through 1k resistor |
| GPIO27 / UART2 RX | ESP32 RX from DFPlayer TX |

## Wiring Checklist

- ESP32 is powered and networked by PoE from the TP-Link LS108GP switch.
- PoE powers the ESP32 controller only. Do not power LED strips, DFPlayer/audio, or speakers from the ESP32 PoE board.
- `5V_LED` positive from the master power distribution goes to the local `5V_LED` rail for the cooktop RGB strip only.
- `5V_AUDIO_SERVO` positive from the master power distribution goes to the local audio rail for DFPlayer/audio only.
- Both 5V rail returns connect to `COMMON_GND`; do not tie the two 5V positives together.
- ESP32 GND connects to the `COMMON_GND` rail wherever LED data, serial, or Hall signals cross power domains.
- Hall sensor VCC pins connect to ESP32 3.3V only, not external +5V.
- Do not feed external +5V into the ESP32 `3V3` pin.
- HALL 1 `AO` connects through an optional 1k series resistor to GPIO20 / ADC1_CH4.
- HALL 2 `AO` connects through an optional 1k series resistor to GPIO21 / ADC1_CH5.
- Use analog Hall sensors such as SS49E, OH49E, or 49E. KY-024 modules are acceptable only when using `AO`.
- Do not use digital-only A3144 / KY-003 sensors for motion scoring.
- Add a 0.1uF capacitor between VCC and GND near each Hall sensor.
- RGB strip `+5V` connects to the `5V_LED` rail.
- RGB strip `GND` connects to `COMMON_GND`.
- ESP32 GPIO23 connects through a 330-470 ohm resistor to RGB strip `DIN`.
- Place a 1000uF electrolytic capacitor across RGB strip +5V and GND near the strip.
- DFPlayer `VCC` connects to the `5V_AUDIO_SERVO` rail.
- DFPlayer `GND` connects to `COMMON_GND`.
- ESP32 GPIO26 / UART2 TX connects through a 1k resistor to DFPlayer `RX`.
- ESP32 GPIO27 / UART2 RX connects directly to DFPlayer `TX`.
- Optional 470uF-1000uF capacitor goes across DFPlayer +5V and GND near the module.
- Speaker connects only to DFPlayer `SPK1` and `SPK2`.
- Do not connect either speaker terminal to GND.
- All grounds must be common where signals cross rails: ESP32, 5V_LED return, 5V_AUDIO_SERVO return, RGB strip, DFPlayer, and Hall sensors.

## Physical Cooktop Checklist

- Mount HALL 1 slightly left of burner center.
- Mount HALL 2 slightly right of burner center.
- Space HALL 1 and HALL 2 about 2.5-3.5 inches apart.
- Keep both Hall sensors under the fake cooktop within the 8-inch pan/burner area.
- Magnet should be hidden in the underside of the pan and offset about 1.5-2.5 inches from pan center.
- Target normal magnet-to-sensor gap is 1/4-1/2 inch.
- Use a thin non-metallic cooktop surface.
- Do not place Hall sensors under a stainless table or thick metal sheet.
- Optional expansion: add HALL 3-5 only if testing shows unreliable motion or dead zones; V1 uses two sensors.

## Firmware Behavior Notes

- At boot or round start, sample a no-pan baseline for both Hall sensors.
- Determine pan present by comparing current readings to the no-pan baseline.
- Sample Hall sensors repeatedly around 30-100 Hz.
- Calculate `motionScore = abs(H1_now - H1_last) + abs(H2_now - H2_last)`.
- Repeated changes above threshold count as pan moving.
- Pan present with motionScore below threshold counts as stationary.
- Accumulate pan active motion time for recipe scoring.
- RGB coil should react immediately to pan presence and movement.
- If pan is present and moving, play sizzle at low/medium volume.
- If pan is present but not moving, gradually increase volume and/or switch to burning track.
- If pan is absent, stop or reduce audio.
- Use forgiving thresholds; this is not precision gesture tracking.

## Assumptions And Part Notes

- Controller assumption: Waveshare ESP32-P4-POE-ETH / ESP32-P4-POE-ETH-NH module powered from the LS108GP over Ethernet.
- ESP32 part: custom editable ESP32-P4 PoE helper part with the module's functional GPIO labels. The Hall pins match the firmware's ESP32-P4 ADC1 map.
- Accessory rail assumption: cooktop LEDs use `5V_LED`; DFPlayer/audio uses `5V_AUDIO_SERVO`; these positives are not tied together.
- DFPlayer Mini, speaker, and electrolytic capacitors use stock Fritzing parts.
- Hall sensors, RGB cooktop coil, rails, supply, 0.1uF capacitors, resistors, physical cooktop layout, and callouts are custom editable Fritzing helper parts for readability.

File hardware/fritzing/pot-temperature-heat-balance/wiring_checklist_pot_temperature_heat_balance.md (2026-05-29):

# Chef Station Pot Temperature / Heat Balance Wiring Checklist

## Pin Assignment Table

| ESP32 pin | Function |
|---|---|
| GPIO32 | Rotary encoder A / CLK |
| GPIO33 | Rotary encoder B / DT |
| GPIO27 | Rotary encoder pushbutton / SW |
| GPIO23 | Cooktop coil RGB strip data through 330-470 ohm resistor |
| GPIO18 | Pot temperature indicator RGB strip/ring data through 330-470 ohm resistor |

## Wiring Checklist

- ESP32 is powered and networked by PoE from the TP-Link LS108GP switch.
- PoE powers the ESP32 controller only. Do not power cooktop LEDs or indicator LEDs from the ESP32 PoE board.
- `5V_LED` positive from the master power distribution goes to the local `5V_LED` rail for the temperature indicator and any 5V cooktop LED strip.
- `5V_LED` return connects to `COMMON_GND`.
- ESP32 GND connects to the `COMMON_GND` rail wherever LED data or encoder signals share external references.
- Cooktop coil strip +5V connects to `5V_LED` if it is a 5V strip. If it is a true 12V strip, connect it to `12V_SHOW` instead and keep only its data/control reference common.
- Cooktop coil strip GND connects to `COMMON_GND`.
- ESP32 GPIO23 connects through a 330-470 ohm resistor to the cooktop coil strip DIN.
- Pot temperature indicator +5V connects to `5V_LED`.
- Pot temperature indicator GND connects to `COMMON_GND`.
- ESP32 GPIO18 connects through a 330-470 ohm resistor to the temperature indicator DIN.
- Place a 1000uF electrolytic capacitor across LED strip +5V and GND near the strip power input.
- Observe electrolytic capacitor polarity.
- Rotary encoder A / CLK connects to GPIO32.
- Rotary encoder B / DT connects to GPIO33.
- Rotary encoder SW connects to GPIO27.
- Rotary encoder common / GND connects to `COMMON_GND`.
- If using a KY-040 style encoder module, connect module VCC to ESP32 3.3V, not `5V_LED` or `12V_SHOW`.
- Use ESP32 `INPUT_PULLUP` for encoder A / CLK, B / DT, and SW.
- Do not feed external +5V into the ESP32 `3V3` pin.
- All grounds must be common where signals cross rails: ESP32, `5V_LED` return, cooktop coil strip, temperature indicator, and encoder.

## Callout Notes

- Common ground: the `5V_LED` return and ESP32 ground must be tied together where LED data crosses power domains.
- External LED power: LED strips use `5V_LED` or `12V_SHOW` by device rating; the ESP32 only provides data signals.
- Encoder INPUT_PULLUP wiring: A / CLK, B / DT, and SW should read HIGH idle and LOW when pulled to COMMON_GND.
- Cooktop coil brightness represents heat setting, not measured temperature.
- Temperature indicator represents simulated pot temperature, not a real sensor reading.
- Score is the percentage of total game time spent in the white/correct zone.

## Firmware Behavior Notes

- Use a fixed game duration, such as 30 or 60 seconds.
- Rotary encoder controls `heatSetting` from 0.0 to 1.0.
- Clockwise rotation increases heat; counterclockwise rotation decreases heat.
- Clamp heat setting from 0-100 percent.
- Cooktop coil color should remain red/orange and vary brightness from `heatSetting`.
- `potTemperature` is simulated, not directly measured.
- Model temperature with velocity/acceleration and damping so it feels physical.
- Higher `heatSetting` increases upward temperature acceleration.
- Lower `heatSetting` allows temperature to fall.
- Add random drift as a slow random walk so the balance point moves over time.
- Random drift should be slow and fair, not sudden or punitive.
- Suggested model: `acceleration = (heatSetting - balancePoint + drift) * tuningFactor`.
- Update `tempVelocity += acceleration * dt`, damp velocity, then update `potTemp += tempVelocity * dt`.
- Constrain `potTemp` to 0.0-1.0.
- `potTemp < 0.42` is TOO COLD / BLUE.
- `0.42 <= potTemp <= 0.58` is CORRECT / WHITE.
- `potTemp > 0.58` is TOO HOT / RED.
- Track milliseconds in the correct zone and total round milliseconds.
- At end of round, report `scorePercent = correctZoneMs / totalGameMs * 100`.
- Example Serial event: `{"station":"chef","module":"pot_temp","event":"score","percent":73}`.

## Game-State Notes

- IDLE: coil dim/off and temperature indicator idle glow.
- ACTIVE: encoder is live and temperature simulation runs.
- SCORING: freeze indicator and report score.
- RESET: clear score, recenter temperature, and recalibrate drift.
- The player should instantly understand that turning the knob changes heat.
- The pot temperature should not stay stable without input.
- The correct/white zone should be forgiving enough for public event use.
- Monitor graphics may show polish and score, but local LEDs should communicate the core gameplay.

## Assumptions And Part Notes

- Controller: diagram uses a custom Waveshare ESP32-P4-POE-ETH / ESP32-P4-POE-ETH-NH PoE helper part.
- The requested ESP32 GPIO function map is preserved on that PoE board helper. Verify exact pin availability before final harness fabrication.
- Accessory rail assumption: temperature LEDs use `5V_LED`; any actual 12V cooktop strip must move to `12V_SHOW`.
- LED strips/rings are represented as custom WS2812B-style helper parts so the +5V, DIN, and GND pins are explicit.
- Rotary encoder is represented as a custom KY-040/bare-encoder helper part so VCC, GND, A/CLK, B/DT, and SW are labeled clearly.
- 1000uF electrolytic capacitor uses the installed Fritzing stock part.
- Resistors, rails, supply, breadboard backplane, LED visuals, encoder, and callout notes are custom editable Fritzing helper parts for readability.

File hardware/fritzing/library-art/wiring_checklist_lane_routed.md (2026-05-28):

# Chef Station Simon Lane-Routed Wiring Checklist

This revision uses editable Fritzing wire segments routed into separated lanes. Long runs are horizontal/vertical, and parallel wires do not share the same line segment. Each button channel now has a visible local GND bus: MOSFET source, switch ground, and pulldown ground branch into that bus, then a single trunk runs to the common GND rail.

## Pin Map

| Button | Switch input | Lamp gate output |
| --- | --- | --- |
| BTN1 / Ingredient 1 | GPIO 16 | GPIO 21 |
| BTN2 / Ingredient 2 | GPIO 17 | GPIO 22 |
| BTN3 / Ingredient 3 | GPIO 18 | GPIO 23 |
| BTN4 / Ingredient 4 | GPIO 19 | GPIO 25 |
| BTN5 / Ingredient 5 | GPIO 26 | GPIO 27 |

## Wiring

- Use the linked uxcell 12V LED illuminated arcade buttons with a 12V lamp/LED rail.
- Tie ESP32 GND, external 12V supply negative, switch ground terminals, MOSFET sources, and pulldown grounds to common ground.
- Feed each arcade button LED + from the shared +12V lamp rail.
- Run each arcade button LED - separately to its own MOSFET drain.
- Connect each MOSFET source to common ground.
- Connect each ESP32 lamp GPIO to its MOSFET gate through a 1k resistor.
- Add a 10k resistor from each MOSFET gate to common ground.
- Wire each button switch with one terminal to GND and the other terminal to its ESP32 input GPIO.
- Connect ESP32 GND to the common GND rail.
- Configure each button input as INPUT_PULLUP: unpressed = HIGH, pressed = LOW.
- Do not connect the LED/lamp negatives together if individual flashing is required.

## Layout Validation

- Fritzing export validation passed.
- Wire audit found 204 editable wire segments.
- Wire audit found 0 diagonal segments.
- Wire audit found 0 zero-length wire segments.
- Wire audit found 0 exact duplicate/overlapping wire segments.
- Separate lanes are used for LED +, LED -, switch signal, switch ground, gate drive, pulldown ground, and MOSFET source ground.
- Ground routing is bus-oriented: each channel uses short local branches plus one trunk to the common GND rail, avoiding split/rejoin ground paths.

## Part Notes

- ESP32: downloaded DOIT ESP32 DevKit V1 Fritzing part.
- Resistors: value-specific Fritzing 1k and 10k resistor artwork, plus visible labels.
- MOSFET: stock Fritzing TO-220 N-channel MOSFET artwork, titled as IRFB11N50APBF.
- Arcade buttons: stock Fritzing arcade button visuals plus labeled 4-position terminal blocks showing LED +, LED -, SW SIG, and SW GND.
- Ground buses: custom annotation/rail helper parts used to make the shared ground topology visually explicit while remaining editable in Fritzing.

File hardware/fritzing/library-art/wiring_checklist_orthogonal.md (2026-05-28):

# Chef Station Simon Orthogonal Wiring Checklist

This revision uses editable Fritzing wire segments routed as horizontal/vertical paths. Long diagonal wires have been replaced with routed segments joined by small editable waypoint nodes.

## Pin Map

| Button | Switch input | Lamp gate output |
| --- | --- | --- |
| BTN1 / Ingredient 1 | GPIO 16 | GPIO 21 |
| BTN2 / Ingredient 2 | GPIO 17 | GPIO 22 |
| BTN3 / Ingredient 3 | GPIO 18 | GPIO 23 |
| BTN4 / Ingredient 4 | GPIO 19 | GPIO 25 |
| BTN5 / Ingredient 5 | GPIO 26 | GPIO 27 |

## Wiring

- Use the linked uxcell 12V LED illuminated arcade buttons with a 12V lamp/LED rail.
- Tie ESP32 GND, external 12V supply negative, switch ground terminals, MOSFET sources, and pulldown grounds to common ground.
- Feed each arcade button LED + from the shared +12V lamp rail.
- Run each arcade button LED - separately to its own MOSFET drain.
- Connect each MOSFET source to common ground.
- Connect each ESP32 lamp GPIO to its MOSFET gate through a 1k resistor.
- Add a 10k resistor from each MOSFET gate to common ground.
- Wire each button switch with one terminal to GND and the other terminal to its ESP32 input GPIO.
- Configure each button input as INPUT_PULLUP: unpressed = HIGH, pressed = LOW.
- Do not connect the LED/lamp negatives together if individual flashing is required.

## Layout Notes

- Wires are split into editable straight Fritzing segments with waypoint nodes.
- Long wire runs are horizontal/vertical; package audit found zero diagonal wire segments.
- Value-specific Fritzing resistor artwork is used for 1k and 10k resistors, with visible value labels.
- ESP32 uses the downloaded DOIT ESP32 DevKit V1 Fritzing part.
- MOSFETs use stock Fritzing TO-220 N-channel MOSFET artwork, titled as IRFB11N50APBF.
- Arcade button visuals use stock Fritzing arcade button artwork plus labeled 4-position terminal blocks for LED +, LED -, SW SIG, and SW GND.

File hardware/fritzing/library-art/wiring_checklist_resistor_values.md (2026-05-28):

# Chef Station Simon Wiring Checklist

This revision uses the latest requested resistor values: 1k gate resistors and 10k gate pulldown resistors. Earlier drafts used the original 100 ohm gate-resistor request.

## Pin Map

| Button | Switch input | Lamp gate output |
| --- | --- | --- |
| BTN1 / Ingredient 1 | GPIO 16 | GPIO 21 |
| BTN2 / Ingredient 2 | GPIO 17 | GPIO 22 |
| BTN3 / Ingredient 3 | GPIO 18 | GPIO 23 |
| BTN4 / Ingredient 4 | GPIO 19 | GPIO 25 |
| BTN5 / Ingredient 5 | GPIO 26 | GPIO 27 |

## Wiring

- Use the linked uxcell 12V LED illuminated arcade buttons with a 12V lamp/LED rail.
- Tie ESP32 GND, external 12V supply negative, switch ground terminals, MOSFET sources, and pulldown grounds to common ground.
- Feed each arcade button LED + from the shared +12V lamp rail.
- Run each arcade button LED - separately to its own MOSFET drain.
- Connect each MOSFET source to common ground.
- Connect each ESP32 lamp GPIO to its MOSFET gate through a 1k resistor.
- Add a 10k resistor from each MOSFET gate to common ground.
- Wire each button switch with one terminal to GND and the other terminal to its ESP32 input GPIO.
- Configure each button input as INPUT_PULLUP: unpressed = HIGH, pressed = LOW.
- Do not connect the LED/lamp negatives together if individual flashing is required.
- IRFB11N50APBF is not logic-level; replace with a logic-level N-channel MOSFET if the LEDs are dim or do not fully turn on.

## Part Notes

- ESP32: downloaded DOIT ESP32 DevKit V1 Fritzing part.
- Resistors: value-specific Fritzing resistor artwork is used for 1k and 10k, with visible labels beside each channel.
- MOSFET: stock Fritzing TO-220 N-channel MOSFET artwork, titled as IRFB11N50APBF.
- Arcade buttons: stock Fritzing arcade button visuals plus labeled 4-position terminal blocks showing LED +, LED -, SW SIG, and SW GND.

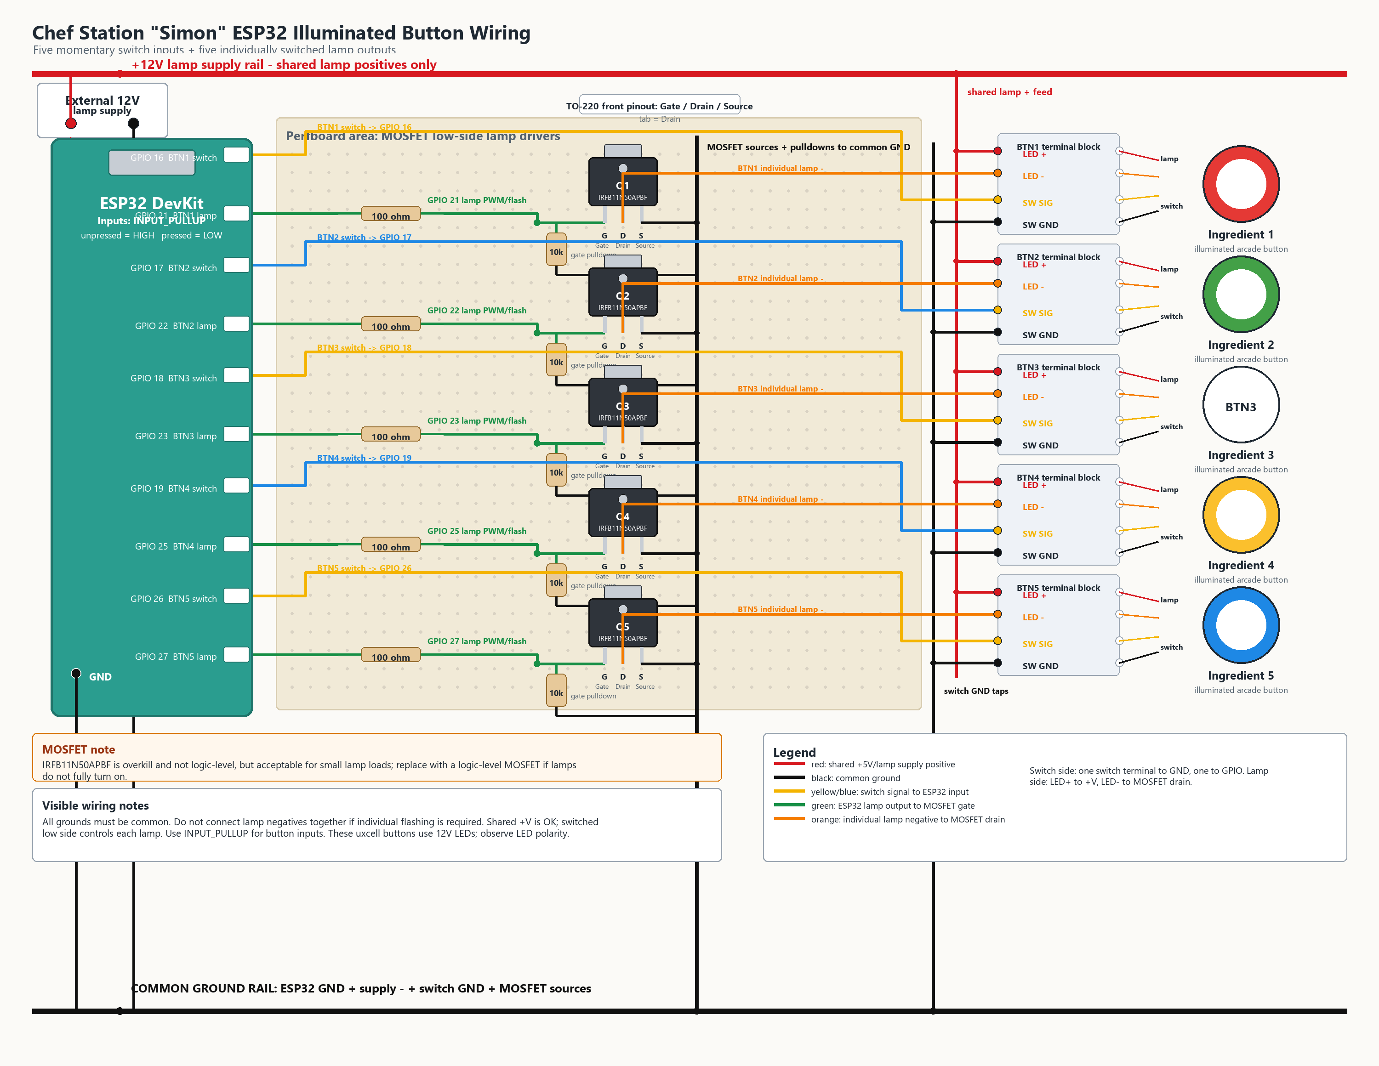
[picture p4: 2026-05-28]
chef_station_simon_wiring_diagram.png

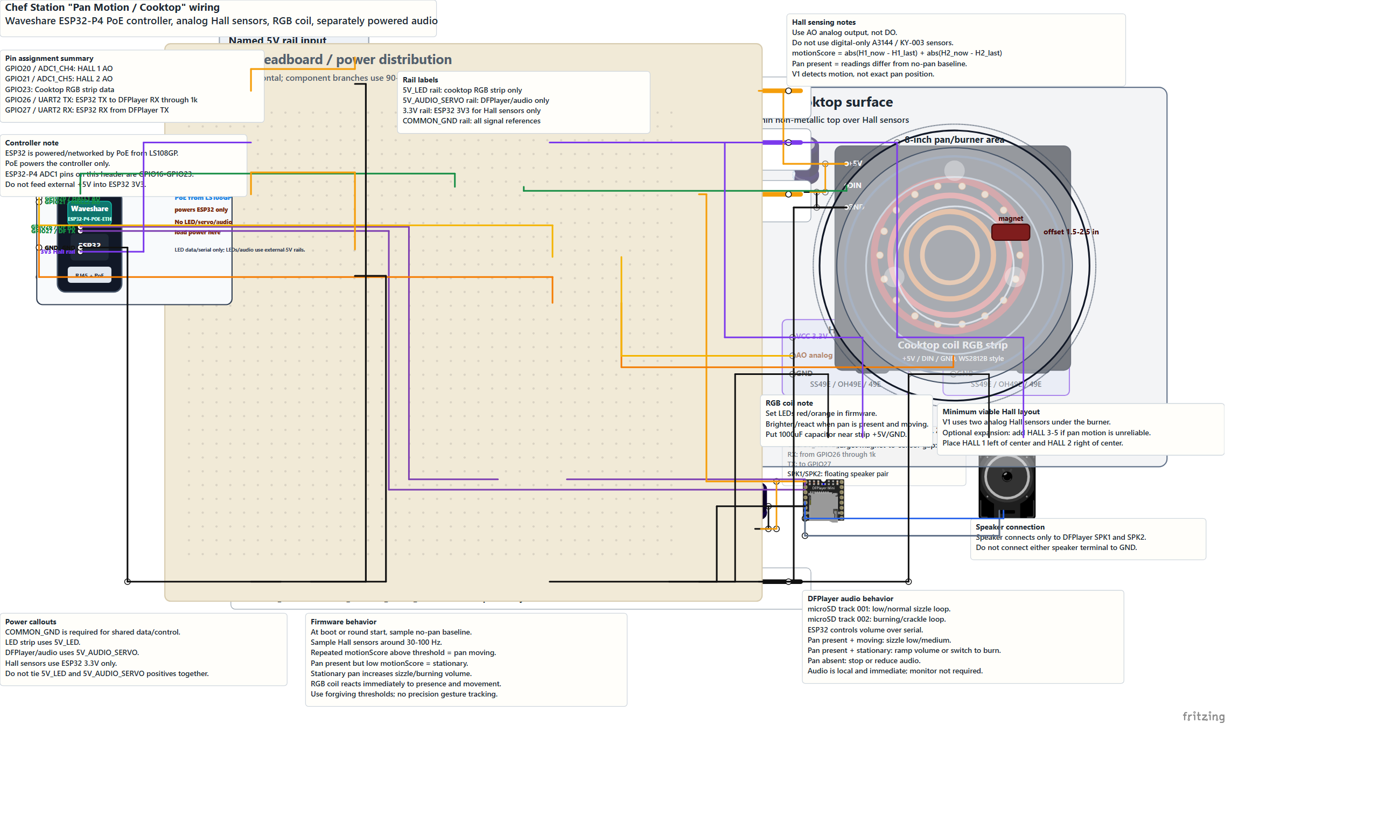
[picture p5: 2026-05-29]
hardware/fritzing/pan-motion-cooktop/chef_station_pan_motion_cooktop_wiring_diagram.png

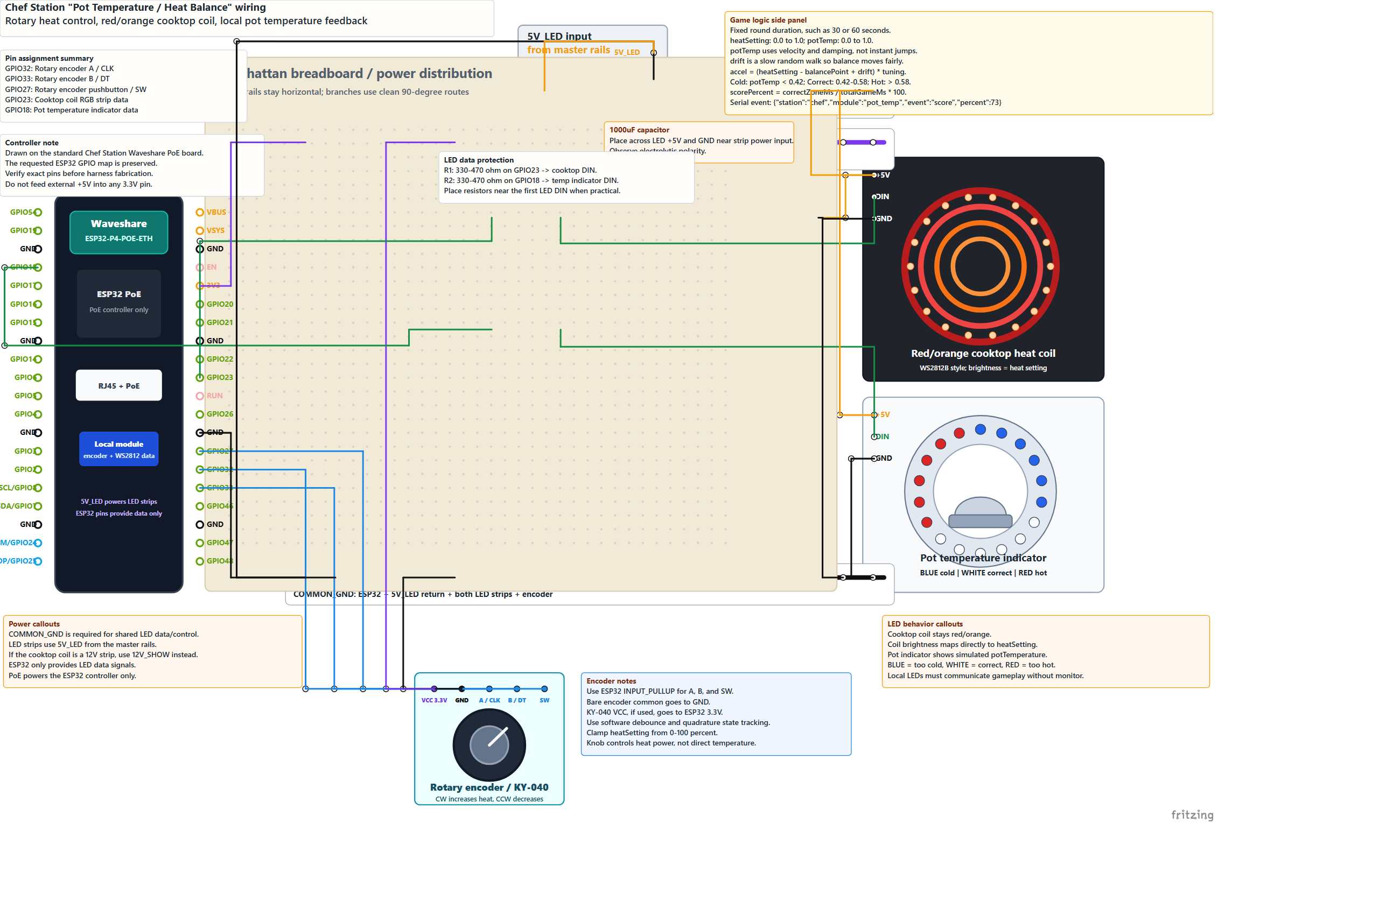
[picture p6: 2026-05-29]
hardware/fritzing/pot-temperature-heat-balance/chef_station_pot_temperature_heat_balance_wiring_diagram.png

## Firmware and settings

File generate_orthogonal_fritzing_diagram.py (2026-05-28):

from __future__ import annotations

import html
import re
import shutil
import subprocess
import zipfile
from dataclasses import dataclass, field
from pathlib import Path


ROOT = Path(__file__).resolve().parent
OUT_DIR = ROOT / "library_art_fritzing"
FZZ_PATH = OUT_DIR / "chef_station_simon_4btn_audio_editable.fzz"
EXPORT_DIR = OUT_DIR / "fritzing_svg_export"
FRITZING = Path(r"C:\Program Files\Fritzing\Fritzing.exe")
PARTS = Path(r"C:\Program Files\Fritzing\fritzing-parts")
ESP32_FZPZ = ROOT / "downloaded_parts" / "DOIT_Esp32_DevKit_v1_improved.fzpz"


BUTTONS = [
    {"n": 1, "name": "Ingredient 1", "sw": "GPIO 16", "lamp": "GPIO 21", "color": "red"},
    {"n": 2, "name": "Ingredient 2", "sw": "GPIO 17", "lamp": "GPIO 22", "color": "green"},
    {"n": 3, "name": "Ingredient 3", "sw": "GPIO 18", "lamp": "GPIO 23", "color": "white"},
    {"n": 4, "name": "Ingredient 4", "sw": "GPIO 19", "lamp": "GPIO 25", "color": "yellow"},
]


STOCK = {
    "resistor_1k": PARTS / "obsolete" / "resistor_1k.fzp",
    "resistor_10k": PARTS / "obsolete" / "resistor_10k.fzp",
    "mosfet": PARTS / "core" / "basic_fet_n.fzp",
    "terminal4": PARTS / "core" / "Camdenboss_CTB0158-4_5_08mm_pitch_90deg_terminals.fzp",
    "speaker": PARTS / "core" / "sparkfun-electromechanical-speaker-.fzp",
    "arcade_red": PARTS / "contrib" / "Arcade_Button__red___c12cc3bca053e12377a7a3c856ef34e4_24.fzp",
    "arcade_yellow": PARTS / "contrib" / "Arcade_Button__yellow___afee1ba07e56f9a78a19f30fa6b24e7f_B2.fzp",
    "arcade_white": PARTS / "contrib" / "Arcade_Button__white___56f11dd8030025047c5ba1044fac4aa2_37.fzp",
    "arcade_blue": PARTS / "contrib" / "Arcade_Button__blue___0c30cbbdde0863c5df34b75e4acddb07_20.fzp",
}


WIRE = {
    "vplus": "#d71920",
    "gnd": "#111111",
    "switch_a": "#f4b400",
    "switch_b": "#1e88e5",
    "gate": "#178f46",
    "lamp_minus": "#f57c00",
    "audio": "#7b1fa2",
    "speaker_pos": "#8d4f16",
    "speaker_neg": "#5f6368",
}


@dataclass
class Part:
    key: str
    module_id: str
    fzp_name: str
    fzp: str
    svg_entries: dict[str, str]
    pins: dict[str, tuple[float, float]]


@dataclass
class Instance:
    key: str
    part: str
    title: str
    x: float
    y: float
    idx: int
    props: dict[str, str] = field(default_factory=dict)
    connects: dict[str, list[tuple[int, str]]] = field(default_factory=dict)


@dataclass
class Wire:
    idx: int
    title: str
    a: str
    ac: str
    b: str
    bc: str
    color: str
    width: float = 10


def esc(value: object) -> str:
    return html.escape(str(value), quote=True)


def read_stock_part(key: str, fzp_path: Path, pins: dict[str, tuple[float, float]]) -> Part:
    fzp = fzp_path.read_text(encoding="utf-8", errors="replace")
    module_id = re.search(r'moduleId="([^"]+)"', fzp).group(1)
    group = fzp_path.parent.name
    svg_entries: dict[str, str] = {}
    for img in re.findall(r'<layers image="([^"]+)"', fzp):
        view, filename = img.split("/", 1)
        candidates = [
            PARTS / "svg" / group / view / filename,
            PARTS / "svg" / "core" / view / filename,
            PARTS / "svg" / "obsolete" / view / filename,
        ]
        source = next((p for p in candidates if p.exists()), candidates[0])
        svg_entries[f"svg.{view}.{filename}"] = source.read_text(encoding="utf-8", errors="replace")
    return Part(key, module_id, f"part.{module_id}.fzp", fzp, svg_entries, pins)


def read_esp32_part() -> Part:
    with zipfile.ZipFile(ESP32_FZPZ) as zf:
        fzp_name = next(n for n in zf.namelist() if n.endswith(".fzp"))
        fzp = zf.read(fzp_name).decode("utf-8", errors="replace")
        module_id = re.search(r'moduleId="([^"]+)"', fzp).group(1)
        svg_entries = {n: zf.read(n).decode("utf-8", errors="replace") for n in zf.namelist() if n.endswith(".svg")}
    # The downloaded ESP32 art uses 1000 SVG units per inch. Fritzing canvas is 72 px/in.
    s = 72 / 1000
    raw = {
        "connector1": (1054.7, 1537.4),  # GND
        "connector5": (1054.5, 1137.4),  # GPIO16 / RX2
        "connector6": (1054.5, 1037.4),  # GPIO17 / TX2
        "connector8": (1054.5, 837.4),   # GPIO18
        "connector9": (1054.5, 737.4),   # GPIO19
        "connector10": (1054.5, 637.4),  # GPIO21
        "connector13": (1054.4, 337.1),  # GPIO22
        "connector14": (1054.5, 237.2),  # GPIO23
        "connector22": (54.5, 937.4),    # GPIO25
        "connector23": (54.5, 1037.4),   # GPIO26
        "connector24": (54.5, 1137.4),   # GPIO27
    }
    pins = {k: (x * s, y * s) for k, (x, y) in raw.items()}
    return Part("esp32", module_id, fzp_name, fzp, svg_entries, pins)


def make_label_part(key: str, text_lines: list[str], width: int = 210, size: int = 15) -> Part:
    height = max(32, 24 + len(text_lines) * (size + 4))
    texts = []
    y = 18
    for i, line in enumerate(text_lines):
        weight = "700" if i == 0 else "500"
        texts.append(
            f'<text x="8" y="{y}" font-family="Segoe UI, Arial, sans-serif" font-size="{size}" '
            f'font-weight="{weight}" fill="#1f2933">{esc(line)}</text>'
        )
        y += size + 5
    svg = f'''<?xml version="1.0" encoding="UTF-8"?>
<svg xmlns="http://www.w3.org/2000/svg" width="{width}" height="{height}" viewBox="0 0 {width} {height}">
  <g id="breadboard"><rect x="0" y="0" width="{width}" height="{height}" rx="5" fill="#fffefa" stroke="#d0d7de"/>{''.join(texts)}</g>
  <g id="schematic"><rect x="0" y="0" width="{width}" height="{height}" rx="5" fill="#fffefa" stroke="#d0d7de"/>{''.join(texts)}</g>
  <g id="silkscreen"><rect x="0" y="0" width="{width}" height="{height}" rx="5" fill="#fffefa" stroke="#d0d7de"/>{''.join(texts)}</g>
  <g id="icon"><rect x="0" y="0" width="{width}" height="{height}" rx="5" fill="#fffefa" stroke="#d0d7de"/>{''.join(texts)}</g>
</svg>
'''
    module_id = f"chef_simon_label_{key}"
    fzp = f'''<?xml version="1.0" encoding="UTF-8"?>
<module fritzingVersion="1.0.3" moduleId="{module_id}">
  <version>1</version><author>OpenAI Codex</author><title>{esc(text_lines[0])}</title><label>TXT</label>
  <properties><property name="family">Chef Simon annotations</property></properties>
  <views>
    <iconView><layers image="icon/{module_id}.svg"><layer layerId="icon"/></layers></iconView>
    <breadboardView><layers image="breadboard/{module_id}.svg"><layer layerId="breadboard"/></layers></breadboardView>
    <schematicView><layers image="schematic/{module_id}.svg"><layer layerId="schematic"/></layers></schematicView>
    <pcbView><layers image="pcb/{module_id}.svg"><layer layerId="silkscreen"/></layers></pcbView>
  </views>
  <connectors/><buses/>
</module>
'''
    return Part(
        key,
        module_id,
        f"part.{module_id}.fzp",
        fzp,
        {
            f"svg.icon.{module_id}.svg": svg,
            f"svg.breadboard.{module_id}.svg": svg,
            f"svg.schematic.{module_id}.svg": svg,
            f"svg.pcb.{module_id}.svg": svg,
        },
        {},
    )


def make_junction_part() -> Part:
    module_id = "chef_simon_wire_waypoint"
    svg = f'''<?xml version="1.0" encoding="UTF-8"?>
<svg xmlns="http://www.w3.org/2000/svg" width="6" height="6" viewBox="0 0 6 6">
  <g id="breadboard"><circle id="pinpin" cx="3" cy="3" r="2" fill="#ffffff" stroke="#6b7280" stroke-width="1"/></g>
  <g id="schematic"><circle id="pinpin" cx="3" cy="3" r="2" fill="#ffffff" stroke="#6b7280" stroke-width="1"/></g>
  <g id="silkscreen"><circle id="pinpin" cx="3" cy="3" r="2" fill="#ffffff" stroke="#6b7280" stroke-width="1"/></g>
  <g id="icon"><circle id="pinpin" cx="3" cy="3" r="2" fill="#ffffff" stroke="#6b7280" stroke-width="1"/></g>
</svg>
'''
    fzp = f'''<?xml version="1.0" encoding="UTF-8"?>
<module fritzingVersion="1.0.3" moduleId="{module_id}">
  <version>1</version><author>OpenAI Codex</author><title>Wire waypoint</title><label>WP</label>
  <properties><property name="family">Chef Simon routing helpers</property></properties>
  <views>
    <iconView><layers image="icon/{module_id}.svg"><layer layerId="icon"/></layers></iconView>
    <breadboardView><layers image="breadboard/{module_id}.svg"><layer layerId="breadboard"/></layers></breadboardView>
    <schematicView><layers image="schematic/{module_id}.svg"><layer layerId="schematic"/></layers></schematicView>
    <pcbView><layers image="pcb/{module_id}.svg"><layer layerId="silkscreen"/></layers></pcbView>
  </views>
  <connectors>
    <connector id="pin" type="male" name="waypoint"><views><breadboardView><p layer="breadboard" svgId="pinpin"/></breadboardView><schematicView><p layer="schematic" svgId="pinpin"/></schematicView><pcbView><p layer="silkscreen" svgId="pinpin"/></pcbView></views></connector>
  </connectors><buses/>
</module>
'''
    return Part(
        "waypoint",
        module_id,
        f"part.{module_id}.fzp",
        fzp,
        {
            f"svg.icon.{module_id}.svg": svg,
            f"svg.breadboard.{module_id}.svg": svg,
            f"svg.schematic.{module_id}.svg": svg,
            f"svg.pcb.{module_id}.svg": svg,
        },
        {"pin": (3, 3)},
    )


def make_rail_part(key: str, title: str, color: str, labels: list[str]) -> Part:
    tap_count = 22
    width = 1260
    connectors = []
    pins = {}
    for i in range(tap_count):
        x = 35 + i * 55
        connectors.append(f'<connector id="tap{i}" type="male" name="tap {i}"><views><breadboardView><p layer="breadboard" svgId="tap{i}pin"/></breadboardView><schematicView><p layer="schematic" svgId="tap{i}pin"/></schematicView><pcbView><p layer="silkscreen" svgId="tap{i}pin"/></pcbView></views></connector>')
        pins[f"tap{i}"] = (x, 24)
    circles = "".join(f'<circle id="tap{i}pin" cx="{35+i*55}" cy="24" r="5" fill="#ffffff" stroke="{color}" stroke-width="2"/>' for i in range(tap_count))
    label_svg = "".join(f'<text x="16" y="{52+i*20}" font-family="Segoe UI, Arial, sans-serif" font-size="15" font-weight="600" fill="#1f2933">{esc(line)}</text>' for i, line in enumerate(labels))
    height = 70 + len(labels) * 20
    svg = f'''<?xml version="1.0" encoding="UTF-8"?>
<svg xmlns="http://www.w3.org/2000/svg" width="{width}" height="{height}" viewBox="0 0 {width} {height}">
  <g id="breadboard"><rect x="0" y="0" width="{width}" height="{height}" rx="8" fill="#ffffff" stroke="#9aa5b1"/><line x1="18" y1="24" x2="{width-18}" y2="24" stroke="{color}" stroke-width="7"/>{circles}{label_svg}</g>
  <g id="schematic"><rect x="0" y="0" width="{width}" height="{height}" rx="8" fill="#ffffff" stroke="#9aa5b1"/><line x1="18" y1="24" x2="{width-18}" y2="24" stroke="{color}" stroke-width="7"/>{circles}{label_svg}</g>
  <g id="silkscreen"><rect x="0" y="0" width="{width}" height="{height}" rx="8" fill="#ffffff" stroke="#9aa5b1"/><line x1="18" y1="24" x2="{width-18}" y2="24" stroke="{color}" stroke-width="7"/>{circles}{label_svg}</g>
  <g id="icon"><rect x="0" y="0" width="{width}" height="{height}" rx="8" fill="#ffffff" stroke="#9aa5b1"/><line x1="18" y1="24" x2="{width-18}" y2="24" stroke="{color}" stroke-width="7"/>{circles}{label_svg}</g>
</svg>
'''
    module_id = f"chef_simon_{key}"
    fzp = f'''<?xml version="1.0" encoding="UTF-8"?>
<module fritzingVersion="1.0.3" moduleId="{module_id}">
  <version>1</version><author>OpenAI Codex</author><title>{esc(title)}</title><label>RAIL</label>
  <properties><property name="family">Chef Simon rails</property></properties>
  <views>
    <iconView><layers image="icon/{module_id}.svg"><layer layerId="icon"/></layers></iconView>
    <breadboardView><layers image="breadboard/{module_id}.svg"><layer layerId="breadboard"/></layers></breadboardView>
    <schematicView><layers image="schematic/{module_id}.svg"><layer layerId="schematic"/></layers></schematicView>
    <pcbView><layers image="pcb/{module_id}.svg"><layer layerId="silkscreen"/></layers></pcbView>
  </views>
  <connectors>{''.join(connectors)}</connectors>
  <buses><bus id="{key}">{''.join(f'<nodeMember connectorId="tap{i}"/>' for i in range(tap_count))}</bus></buses>
</module>
'''
    return Part(
        key,
        module_id,
        f"part.{module_id}.fzp",
        fzp,
        {
            f"svg.icon.{module_id}.svg": svg,
            f"svg.breadboard.{module_id}.svg": svg,
            f"svg.schematic.{module_id}.svg": svg,
            f"svg.pcb.{module_id}.svg": svg,
        },
        pins,
    )


def make_local_ground_bus_part() -> Part:
    module_id = "chef_simon_local_ground_bus"
    width = 560
    height = 62
    tap_xs = [30, 130, 230, 330, 430, 530]
    connectors = []
    pins = {}
    for i, x in enumerate(tap_xs):
        connectors.append(f'<connector id="tap{i}" type="male" name="ground tap {i}"><views><breadboardView><p layer="breadboard" svgId="tap{i}pin"/></breadboardView><schematicView><p layer="schematic" svgId="tap{i}pin"/></schematicView><pcbView><p layer="silkscreen" svgId="tap{i}pin"/></pcbView></views></connector>')
        pins[f"tap{i}"] = (x, 20)
    circles = "".join(f'<circle id="tap{i}pin" cx="{x}" cy="20" r="5" fill="#ffffff" stroke="{WIRE["gnd"]}" stroke-width="2"/>' for i, x in enumerate(tap_xs))
    svg = f'''<?xml version="1.0" encoding="UTF-8"?>
<svg xmlns="http://www.w3.org/2000/svg" width="{width}" height="{height}" viewBox="0 0 {width} {height}">
  <g id="breadboard"><rect x="0" y="0" width="{width}" height="{height}" rx="6" fill="#ffffff" stroke="#9aa5b1"/><line x1="16" y1="20" x2="{width-16}" y2="20" stroke="{WIRE["gnd"]}" stroke-width="6"/>{circles}<text x="16" y="48" font-family="Segoe UI, Arial, sans-serif" font-size="14" font-weight="700" fill="#1f2933">local GND bus: branches only, one trunk to common rail</text></g>
  <g id="schematic"><rect x="0" y="0" width="{width}" height="{height}" rx="6" fill="#ffffff" stroke="#9aa5b1"/><line x1="16" y1="20" x2="{width-16}" y2="20" stroke="{WIRE["gnd"]}" stroke-width="6"/>{circles}<text x="16" y="48" font-family="Segoe UI, Arial, sans-serif" font-size="14" font-weight="700" fill="#1f2933">local GND bus: branches only, one trunk to common rail</text></g>
  <g id="silkscreen"><rect x="0" y="0" width="{width}" height="{height}" rx="6" fill="#ffffff" stroke="#9aa5b1"/><line x1="16" y1="20" x2="{width-16}" y2="20" stroke="{WIRE["gnd"]}" stroke-width="6"/>{circles}<text x="16" y="48" font-family="Segoe UI, Arial, sans-serif" font-size="14" font-weight="700" fill="#1f2933">local GND bus: branches only, one trunk to common rail</text></g>
  <g id="icon"><rect x="0" y="0" width="{width}" height="{height}" rx="6" fill="#ffffff" stroke="#9aa5b1"/><line x1="16" y1="20" x2="{width-16}" y2="20" stroke="{WIRE["gnd"]}" stroke-width="6"/>{circles}<text x="16" y="48" font-family="Segoe UI, Arial, sans-serif" font-size="14" font-weight="700" fill="#1f2933">local GND bus: branches only, one trunk to common rail</text></g>
</svg>
'''
    fzp = f'''<?xml version="1.0" encoding="UTF-8"?>
<module fritzingVersion="1.0.3" moduleId="{module_id}">
  <version>1</version><author>OpenAI Codex</author><title>Local GND bus</title><label>GND</label>
  <properties><property name="family">Chef Simon rails</property></properties>
  <views>
    <iconView><layers image="icon/{module_id}.svg"><layer layerId="icon"/></layers></iconView>
    <breadboardView><layers image="breadboard/{module_id}.svg"><layer layerId="breadboard"/></layers></breadboardView>
    <schematicView><layers image="schematic/{module_id}.svg"><layer layerId="schematic"/></layers></schematicView>
    <pcbView><layers image="pcb/{module_id}.svg"><layer layerId="silkscreen"/></layers></pcbView>
  </views>
  <connectors>{''.join(connectors)}</connectors>
  <buses><bus id="local_ground">{''.join(f'<nodeMember connectorId="tap{i}"/>' for i in range(len(tap_xs)))}</bus></buses>
</module>
'''
    return Part(
        "local_gnd_bus",
        module_id,
        f"part.{module_id}.fzp",
        fzp,
        {
            f"svg.icon.{module_id}.svg": svg,
            f"svg.breadboard.{module_id}.svg": svg,
            f"svg.schematic.{module_id}.svg": svg,
            f"svg.pcb.{module_id}.svg": svg,
        },
        pins,
    )


def make_pam8403_part() -> Part:
    module_id = "chef_simon_generic_pam8403_mini_amp"
    width = 280
    height = 180
    pins = {
        "lin": (10, 50),
        "in_gnd": (10, 90),
        "rin": (10, 130),
        "vcc": (105, 10),
        "pwr_gnd": (155, 10),
        "lplus": (270, 48),
        "lminus": (270, 82),
        "rplus": (270, 118),
        "rminus": (270, 152),
    }
    circles = "".join(
        f'<circle id="{pin}pin" cx="{x}" cy="{y}" r="5" fill="#ffffff" stroke="#374151" stroke-width="2"/>'
        for pin, (x, y) in pins.items()
    )
    labels = [
        ("L IN", 22, 54), ("IN GND", 22, 94), ("R IN", 22, 134),
        ("5V", 92, 28), ("GND", 139, 28),
        ("L+", 235, 52), ("L-", 235, 86), ("R+", 235, 122), ("R-", 235, 156),
    ]
    label_svg = "".join(
        f'<text x="{x}" y="{y}" font-family="Segoe UI, Arial, sans-serif" font-size="12" font-weight="700" fill="#111827">{esc(text)}</text>'
        for text, x, y in labels
    )
    svg = f'''<?xml version="1.0" encoding="UTF-8"?>
<svg xmlns="http://www.w3.org/2000/svg" width="{width}" height="{height}" viewBox="0 0 {width} {height}">
  <g id="breadboard">
    <rect x="0" y="0" width="{width}" height="{height}" rx="8" fill="#2f80ed" stroke="#1f4f9a" stroke-width="2"/>
    <rect x="84" y="60" width="112" height="58" rx="4" fill="#1f2937" stroke="#111827"/>
    <text x="88" y="84" font-family="Segoe UI, Arial, sans-serif" font-size="16" font-weight="800" fill="#ffffff">PAM8403</text>
    <text x="96" y="104" font-family="Segoe UI, Arial, sans-serif" font-size="11" font-weight="700" fill="#dbeafe">5V stereo amp</text>
    {circles}{label_svg}
  </g>
  <g id="schematic">
    <rect x="0" y="0" width="{width}" height="{height}" rx="8" fill="#2f80ed" stroke="#1f4f9a" stroke-width="2"/>
    <rect x="84" y="60" width="112" height="58" rx="4" fill="#1f2937" stroke="#111827"/>
    <text x="88" y="84" font-family="Segoe UI, Arial, sans-serif" font-size="16" font-weight="800" fill="#ffffff">PAM8403</text>
    <text x="96" y="104" font-family="Segoe UI, Arial, sans-serif" font-size="11" font-weight="700" fill="#dbeafe">5V stereo amp</text>
    {circles}{label_svg}
  </g>
  <g id="silkscreen">
    <rect x="0" y="0" width="{width}" height="{height}" rx="8" fill="#2f80ed" stroke="#1f4f9a" stroke-width="2"/>
    <rect x="84" y="60" width="112" height="58" rx="4" fill="#1f2937" stroke="#111827"/>
    <text x="88" y="84" font-family="Segoe UI, Arial, sans-serif" font-size="16" font-weight="800" fill="#ffffff">PAM8403</text>
    <text x="96" y="104" font-family="Segoe UI, Arial, sans-serif" font-size="11" font-weight="700" fill="#dbeafe">5V stereo amp</text>
    {circles}{label_svg}
  </g>
  <g id="icon">
    <rect x="0" y="0" width="{width}" height="{height}" rx="8" fill="#2f80ed" stroke="#1f4f9a" stroke-width="2"/>
    <rect x="84" y="60" width="112" height="58" rx="4" fill="#1f2937" stroke="#111827"/>
    <text x="88" y="84" font-family="Segoe UI, Arial, sans-serif" font-size="16" font-weight="800" fill="#ffffff">PAM8403</text>
    <text x="96" y="104" font-family="Segoe UI, Arial, sans-serif" font-size="11" font-weight="700" fill="#dbeafe">5V stereo amp</text>
    {circles}{label_svg}
  </g>
</svg>
'''
    connector_xml = "".join(
        f'<connector id="{pin}" type="male" name="{pin}"><views><breadboardView><p layer="breadboard" svgId="{pin}pin"/></breadboardView><schematicView><p layer="schematic" svgId="{pin}pin"/></schematicView><pcbView><p layer="silkscreen" svgId="{pin}pin"/></pcbView></views></connector>'
        for pin in pins
    )
    fzp = f'''<?xml version="1.0" encoding="UTF-8"?>
<module fritzingVersion="1.0.3" moduleId="{module_id}">
  <version>1</version><author>OpenAI Codex</author><title>Generic PAM8403 5V mini amplifier</title><label>AMP</label>
  <properties><property name="family">PAM8403 mini amplifier</property><property name="part number">PAM8403</property></properties>
  <views>
    <iconView><layers image="icon/{module_id}.svg"><layer layerId="icon"/></layers></iconView>
    <breadboardView><layers image="breadboard/{module_id}.svg"><layer layerId="breadboard"/></layers></breadboardView>
    <schematicView><layers image="schematic/{module_id}.svg"><layer layerId="schematic"/></layers></schematicView>
    <pcbView><layers image="pcb/{module_id}.svg"><layer layerId="silkscreen"/></layers></pcbView>
  </views>
  <connectors>{connector_xml}</connectors>
  <buses/>
</module>
'''
    return Part(
        "pam8403",
        module_id,
        f"part.{module_id}.fzp",
        fzp,
        {
            f"svg.icon.{module_id}.svg": svg,
            f"svg.breadboard.{module_id}.svg": svg,
            f"svg.schematic.{module_id}.svg": svg,
            f"svg.pcb.{module_id}.svg": svg,
        },
        pins,
    )


def uniquify_svg_entries(part: Part) -> Part:
    renamed_entries = {}
    for old_entry, svg_text in part.svg_entries.items():
        view = old_entry.split(".")[1]
        old_file = old_entry.split(".", 2)[2]
        new_file = f"{part.module_id}_{view}.svg"
        part.fzp = part.fzp.replace(f"{view}/{old_file}", f"{view}/{new_file}")
        renamed_entries[f"svg.{view}.{new_file}"] = svg_text
    part.svg_entries = renamed_entries
    return part
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

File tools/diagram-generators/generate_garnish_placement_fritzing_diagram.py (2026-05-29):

from __future__ import annotations

import html
import re
import shutil
import subprocess
import zipfile
from dataclasses import dataclass, field
from pathlib import Path

from module_protocol_helpers import make_protocol_esp32_poe_part


PROJECT_ROOT = Path(__file__).resolve().parents[2]
OUT_DIR = PROJECT_ROOT / "hardware" / "fritzing" / "garnish-placement"
FZZ_PATH = OUT_DIR / "chef_station_garnish_placement_editable.fzz"
EXPORT_DIR = OUT_DIR / "fritzing_svg_export"
PNG_PATH = OUT_DIR / "chef_station_garnish_placement_wiring_diagram.png"
CHECKLIST_PATH = OUT_DIR / "wiring_checklist_garnish_placement.md"
FRITZING = Path(r"C:\Program Files\Fritzing\Fritzing.exe")
EDGE = Path(r"C:\Program Files (x86)\Microsoft\Edge\Application\msedge.exe")
PARTS = Path(r"C:\Program Files\Fritzing\fritzing-parts")


WIRE = {
    "vplus": "#f59e0b",
    "gnd": "#111111",
    "control": "#178f46",
    "ethernet": "#1e88e5",
    "touch_center": "#f4b400",
    "touch_inner": "#f57c00",
    "touch_outer": "#c76b00",
    "button": "#1e88e5",
}


@dataclass
class Connector:
    cid: str
    name: str
    x: float
    y: float
    color: str = "#ffffff"


@dataclass
class Part:
    key: str
    module_id: str
    fzp_name: str
    fzp: str
    svg_entries: dict[str, str]
    pins: dict[str, tuple[float, float]]


@dataclass
class Instance:
    key: str
    part: str
    title: str
    x: float
    y: float
    idx: int
    props: dict[str, str] = field(default_factory=dict)
    connects: dict[str, list[tuple[int, str]]] = field(default_factory=dict)
    z: float = 2


@dataclass
class Wire:
    idx: int
    title: str
    a: str
    ac: str
    b: str
    bc: str
    color: str
    width: float = 9


parts_dynamic: dict[str, Part] = {}


def esc(value: object) -> str:
    return html.escape(str(value), quote=True)


def read_stock_part(key: str, fzp_path: Path, pins: dict[str, tuple[float, float]]) -> Part:
    fzp = fzp_path.read_text(encoding="utf-8", errors="replace")
    module_id = re.search(r'moduleId="([^"]+)"', fzp).group(1)
    group = fzp_path.parent.name
    svg_entries: dict[str, str] = {}
    for img in re.findall(r'<layers image="([^"]+)"', fzp):
        view, filename = img.split("/", 1)
        candidates = [
            PARTS / "svg" / group / view / filename,
            PARTS / "svg" / "core" / view / filename,
            PARTS / "svg" / "obsolete" / view / filename,
            PARTS / "svg" / "contrib" / view / filename,
        ]
        source = next((p for p in candidates if p.exists()), candidates[0])
        svg_entries[f"svg.{view}.{filename}"] = source.read_text(encoding="utf-8", errors="replace")
    return Part(key, module_id, f"part.{module_id}.fzp", fzp, svg_entries, pins)


def read_esp32_part() -> Part:
    s = 72 / 1000
    raw = {
        "connector1": (1054.7, 1537.4),  # GND
        "connector14": (1054.5, 237.2),  # GPIO23
        "connector20": (54.5, 737.4),    # GPIO2 / TOUCH CH1
        "connector21": (54.5, 837.4),    # GPIO3 / TOUCH CH2
        "connector22": (54.5, 937.4),    # GPIO32
        "connector23": (54.5, 1037.4),   # GPIO26
        "connector24": (54.5, 1137.4),   # GPIO6 / TOUCH CH5
    }
    pins = {k: (x * s, y * s) for k, (x, y) in raw.items()}
    labels = {
        "connector1": "GND",
        "connector14": "GPIO23 / LED DATA",
        "connector20": "GPIO2 / CENTER",
        "connector21": "GPIO3 / INNER",
        "connector22": "GPIO32 / SERVO SIG",
        "connector23": "GPIO26 / DONE",
        "connector24": "GPIO6 / OUTER",
    }
    return make_protocol_esp32_poe_part(
        custom_part=custom_part,
        connector_cls=Connector,
        key="waveshare_esp32_poe_eth",
        title="Waveshare ESP32-P4-POE-ETH / ESP32-P4-POE-ETH-NH",
        pins=pins,
        labels=labels,
        wire=WIRE,
        family="Chef Station Garnish Placement",
        extra_note="Touch/GPIO/data only; LED and servo use external 5V rails.",
    )


def uniquify_svg_entries(part: Part) -> Part:
    renamed_entries = {}
    for old_entry, svg_text in part.svg_entries.items():
        view = old_entry.split(".")[1]
        old_file = old_entry.split(".", 2)[2]
        new_file = f"{part.module_id}_{view}.svg"
        part.fzp = part.fzp.replace(f"{view}/{old_file}", f"{view}/{new_file}")
        renamed_entries[f"svg.{view}.{new_file}"] = svg_text
    part.svg_entries = renamed_entries
    return part


def text(x: float, y: float, value: str, size: int = 14, fill: str = "#1f2933", weight: int = 600, anchor: str = "start") -> str:
    return (
        f'<text x="{x}" y="{y}" font-family="Segoe UI, Arial, sans-serif" font-size="{size}" '
        f'font-weight="{weight}" fill="{fill}" text-anchor="{anchor}">{esc(value)}</text>'
    )
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

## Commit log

2026-05-28 Initial Chef Station wiring assets
    [chef_station_simon_4btn_audio_editable.fzz, chef_station_simon_lane_routed_editable.fzz, chef_station_simon_library_art_editable.fzz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]
2026-05-29 Organize Chef Station project scaffold
    [chef_station_simon_4btn_audio_editable.fzz, chef_station_simon_lane_routed_editable.fzz, chef_station_simon_library_art_editable.fzz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]
2026-05-29 Add Chef Station build wiring diagrams
    [chef_station_chopping_module_editable.fzz, chef_station_garnish_placement_editable.fzz, chef_station_master_controller_score_print_editable.fzz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]
2026-05-29 Remove Pi from build wiring diagrams
    [chef_station_master_controller_score_print_editable.fzz, chef_station_master_power_network_editable.fzz]
2026-05-29 Add master controller pin hookup
    [chef_station_master_power_network_editable.fzz]
